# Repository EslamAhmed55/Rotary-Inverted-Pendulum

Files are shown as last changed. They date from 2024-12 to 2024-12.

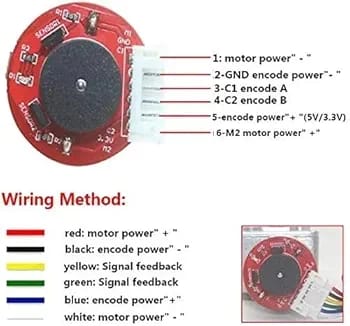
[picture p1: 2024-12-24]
HIL/Simulink/Motor Encoder.jpeg

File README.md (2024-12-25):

# Rotary Inverted Pendulum

## Overview
The **Rotary Inverted Pendulum** 
is a classic control systems project designed to model, simulate, and control a challenging mechanical system.
The system combines mechanical, electrical, and software components to achieve stabilization through advanced control techniques.

---

## Objectives
1. Develop a rotary inverted pendulum system as a demonstration of control engineering principles.
2. Model the system dynamics using Newton's Laws(for Simulation) and Euler-Lagrange(for HIL) methods.
3. Accurately estimate system parameters for reliable control.
4. Design and integrate mechanical components with an electronic control system.
5. Implement a Linear Quadratic Regulator (LQR) for stabilization.
6. Validate through simulation and Hardware-in-the-Loop (HIL) testing.
   


---

## Components
### Hardware
- **Arduino Uno**: Central processing unit for signal processing and control.
- **DC Motor with Encoder**: Provides rotational motion with position feedback.
- **Rotary Incremental Encoder**: Measures angular displacement and velocity.
- **H-Bridge**: Motor driver for bidirectional control.
- **Batteries, Bearings, and Couplings**: Supporting hardware for the system.
- **3D-Printed Parts**: Custom components like brackets and spacers.

  

---

### Software
- **SolidWorks**: For mechanical design and CAD modeling.
- **MATLAB & Simulink**: For simulation, parameter estimation, and HIL testing.

---

## Mechanical Design
The system includes:
1. **Base Structure**: Ensures stability and minimal vibration.
2. **Pendulum & Coupling**: Designed for smooth motion transmission.
3. **Bearing Assembly**: Reduces friction and aligns mechanical components.
4. **Motor and Encoder Mounts**: Ensures precise alignment and feedback.



---

## Hardware Circuit
The circuit integrates all components, ensuring seamless communication and precise control. Key considerations include:
- Proper grounding to minimize noise.
- Organized wiring for reduced interference.
- Overcurrent protection and thermal management.
  
  

---

## Parameter Estimation
System parameters were estimated by:
1. Collecting voltage and angular velocity data.
2. Using MATLAB's Parameter Estimation Toolbox.
3. Modeling and validating results in Simulink.
   
   
   
   

---

## Control Design
The project employs an **LQR Controller**:
1. Models the system dynamics and ensures controllability.
2. Minimizes a cost function to balance state performance and control effort.
3. Stabilizes the pendulum by placing system poles in the left-hand plane.

---
## Simulation

Simulations were conducted in MATLAB to:
1. Verify the system’s unstable dynamics.
2. Test the LQR controller for stability and performance.
3. Validate results with HIL testing using real hardware.

https://github.com/user-attachments/assets/a0bc8a6b-0416-4e09-b2ac-d904dfb135ff

---
## Hardware-in-the-Loop (HIL)

Hardware-in-the-Loop (HIL) testing was used to validate the system’s performance by integrating the control algorithm with real-world hardware. Using Simulink and the Arduino support package, the following steps were undertaken:
1. **Real-Time Simulation**: The controller algorithm was executed on a Simulink model interfaced with the Arduino.
2. **Hardware Validation**: Physical components, including the motor, encoder, and pendulum, were tested under real-world conditions.
3. **Testing and Refinement**: The results were analyzed to refine the control strategy and improve system stability.

   Capture

### Video Demonstration

https://github.com/user-attachments/assets/2c234a89-eb0c-4679-b708-453d3e55b6c0

---

## Resources
1. Research Paper: [Modeling and control of a rotary inverted pendulum](https://ieeexplore.ieee.org/document/5589450)
2. MATLAB Documentation: [LQR Control](https://www.mathworks.com/help/control/ref/lti.lqr.html)
3. Video Resources:
   - [Classic Inverted Pendulum - Equations of Motion](https://www.youtube.com/watch?v=5qJY-ZaKSic)
   - [LQR Controller Implementation](https://www.youtube.com/watch?v=E_RDCFOlJx4)

---

## Acknowledgments
I would like to extend my heartfelt gratitude to **Eng.Ahmed Farag** and **Eng.Ibrahim Abdelghafar** and **Eng.Mohab Ahmed Ali** for their invaluable guidance, support, and expertise throughout the project. Their assistance played a pivotal role in the successful completion of this work.

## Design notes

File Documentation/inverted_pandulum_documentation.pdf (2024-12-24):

# Mechatronics System

# Project: Rotary Inverted Pendulum Project

### Table of Contents

Objectives | 2
Components | 3
Mechanical design | 0
Hardware Circuit | 2
Parameter Estimation Steps | 3
Modelling | 8
1- Newton’s Laws | 8
2- Euler-Lagrange Method | 11
Control Design | 12
Simulation | 15
Hardware in the Loop | 17
Resources | 18

## Objectives

The rotary inverted pendulum is a widely recognized benchmark system in control engineering, known for its challenging dynamics and applications in advanced control design. This project aims to integrate mechanical, electrical, and software components to model, simulate, and control the system effectively. The following objectives outline the key aspects of the project: Develop a rotary inverted pendulum system to serve as a practical demonstration of advanced control engineering principles.

- Explore system modeling through Newton's Method and Lagrangian dynamics for a deeper understanding of mechanical behavior.
- Estimate system parameters accurately to ensure reliable modeling and control.
- Design and implement an efficient hardware circuit and integrate mechanical components with electronic control.
- Apply an LQR controller for stabilization, highlighting the principles of control design.
- Validate the control strategy through simulation and Hardware-in-the-Loop (HIL) testing.
- Document and utilize resources effectively to ensure the project's success.

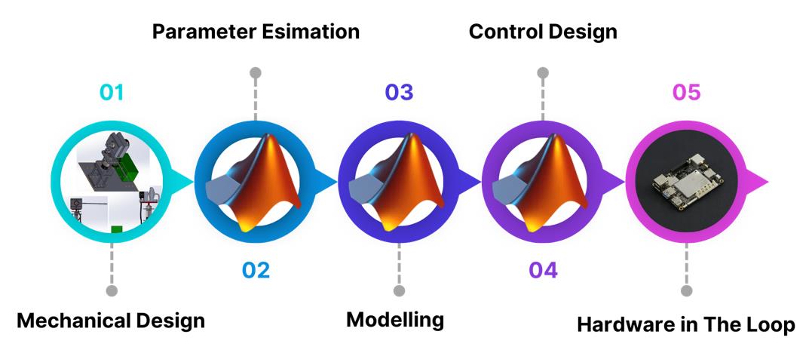
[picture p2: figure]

## Components

The hardware components used are:

❖ Arduino Uno

- A microcontroller board based on the
ATmega328P.

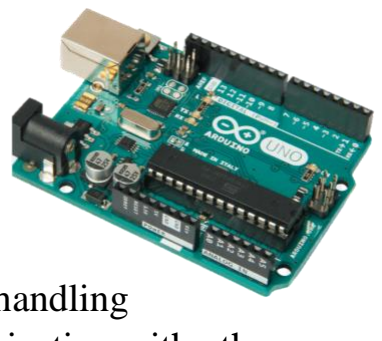
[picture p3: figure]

- Acts as the central processing unit for the system, handling
signal processing, control algorithms, and communication with other components.

❖ DC Motor with Encoder

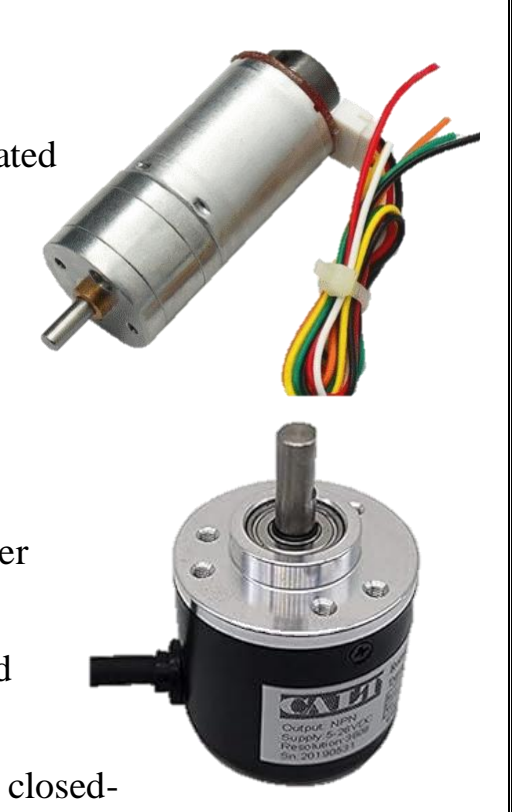
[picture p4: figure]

- A brushed DC motor equipped with an integrated encoder for precise speed and position feedback.
- Provides rotational motion to the pendulum base and enables control of its angular position.

❖ Rotary Incremental Encoder

- A high-resolution encoder with 1200 pulses per revolution (PPR).
- Used to measure the angular displacement and velocity of the pendulum.
- Provides essential feedback for implementing closed-loop control.

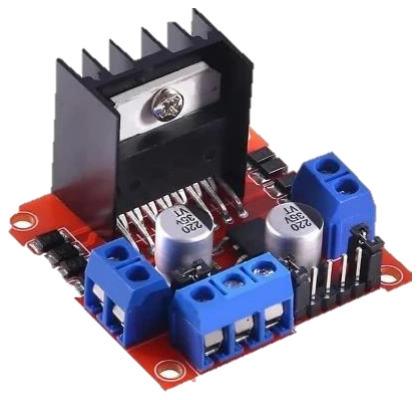
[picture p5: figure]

❖ H-Bridge

- A motor driver circuit that allows bidirectional control of the DC motor.

❖ 3 lithium Batteries

❖ Wires

❖ Bearing

❖ Coupling

❖ Pendulum

❖ 3D-Printing

❖ Spacers

## Mechanical design

The mechanical design of the rotary inverted pendulum was meticulously developed using SolidWorks, a powerful CAD software. The design process focused on creating a lightweight, precise, and stable structure capable of supporting the system's dynamic requirements. The following key components were modeled and integrated:

1. Base Structure
- Designed to provide a stable foundation for the pendulum system.
- Accommodates the DC motor, bearing, and other critical components.
- Ensures minimal vibrations and consistent performance during operation.
2. Pendulum
- Attached to the rotational axis with a secure coupling mechanism to ensure smooth motion.
3. Bearing Assembly
- Incorporated to reduce friction at the rotary axis and enable precise rotational motion.
- Positioned to align with the motor shaft for optimal mechanical efficiency.
4. Motor and Encoder Mount
- Custom brackets were designed to securely hold the DC motor and rotary incremental encoder.
- Ensures accurate alignment for precise feedback and smooth operation.
5. Coupling
- Designed to transmit torque from the motor shaft to the pendulum base with minimal energy loss.
- Accounts for minor misalignments to prevent undue stress on the motor or pendulum.
6. Spacer and Support Structures
- Used to maintain proper alignment and spacing between components.
- Ensures a compact and efficient layout for the entire system.
7. 3D-Printed Components
- Custom parts, including mounting brackets, pendulum holders, and spacers, were fabricated using 3D printing.

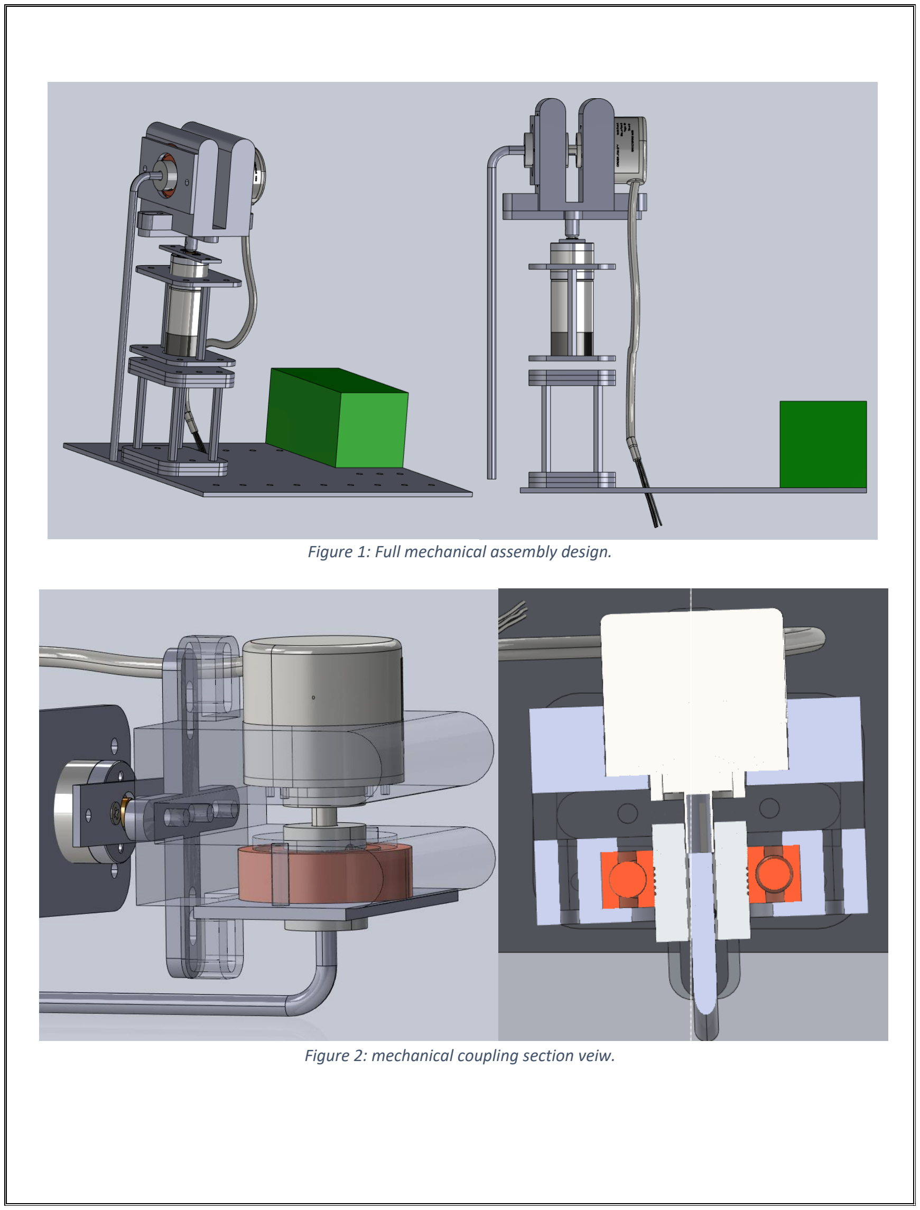
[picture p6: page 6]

Figure 1: Full mechanical assembly design.

Figure 2: mechanical coupling section veiw.

## Hardware Circuit

The hardware circuit for the rotary inverted pendulum system was designed to integrate all electrical components seamlessly, enabling precise control and stability. It connects the control unit, actuators, and feedback devices in a reliable and efficient manner.

Circuit Design Overview

- The Arduino Uno processes feedback signals from the rotary incremental encoder and implements the LQR control algorithm.
- The H-Bridge motor driver regulates the speed and direction of the DC motor based on PWM signals from the Arduino.
- The rotary encoder provides high-resolution position and velocity feedback, critical for accurate control.
- The power system, comprising lithium batteries, supplies sufficient energy to both the Arduino and the motor driver.

Wiring and Connections

- The motor driver is connected to the Arduino's PWM pins for motor speed control.
- The encoder outputs are linked to the Arduino's interrupt pins to capture high-frequency feedback signals.
- A dedicated power line is used for the motor driver to prevent noise interference with the Arduino.

Key Considerations

- Proper grounding was established to minimize noise and ensure signal integrity.
- Wiring was organized to prevent cross-interference, with signal and power lines routed separately.
- A heat sink was added to the H-Bridge to handle thermal loads during extended operation.
- Overcurrent protection was implemented to safeguard components during sudden load changes.

The hardware circuit ensures smooth communication between components, translating control commands into precise physical actions to stabilize the pendulum effectively.

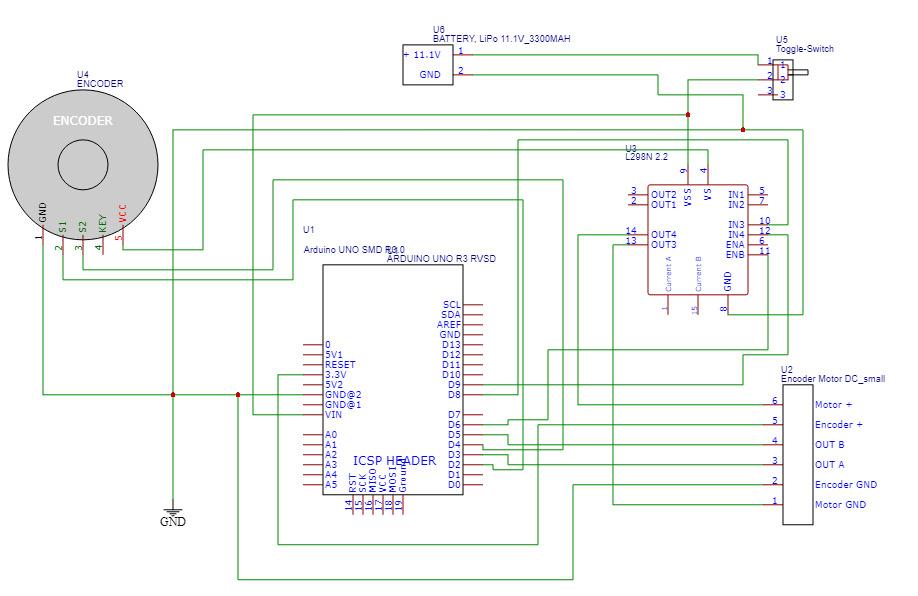
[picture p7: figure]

## Parameter Estimation Steps

Parameter estimation of a DC motor involves determining the values of various electrical and mechanical parameters that characterize the motor's behavior. These parameters are crucial for creating an accurate mathematical model of the DC motor, which is essential for designing effective control strategies. Parameter Estimation for the motor to get the motor coefficients:

- give the motor a Different Voltage signals using this circuit.

This circuit demonstrates how to control a DC motor with an encoder using variable voltage levels, generated by a potentiometer, for parameter estimation. Here's a brief explanation:

Components and Functionality:

1. Arduino UNO: Acts as the central microcontroller for reading signals and possibly controlling the system.
2. Battery (12V): Provides the primary power source for the DC motor.

Figure 3: Hardware circuit using easyEDA.

3. DC Motor with Encoder: The motor's encoder provides feedback on the rotational position or speed for parameter estimation.
4. Potentiometer: Used to vary the voltage signal that controls the motor speed.
5. Ammeter (Multimeter): Measures the current flow in the circuit, allowing calculation of motor parameters like resistance and torque constant.

Working:

- The potentiometer adjusts the voltage sent to the motor, enabling the control of motor speed.
- The Arduino reads encoder feedback to analyze the motor's response to the applied voltage.
- The ammeter monitors the current, aiding in parameter estimation such as motor resistance, inductance, and back EMF.
- The battery provides the required power for motor operation, while the Arduino manages low-power signal processing.

This setup helps in deriving key parameters of the motor, such as its torque constant, electrical resistance, and moment of inertia, by analyzing the relationship between voltage, current, and rotational speed.

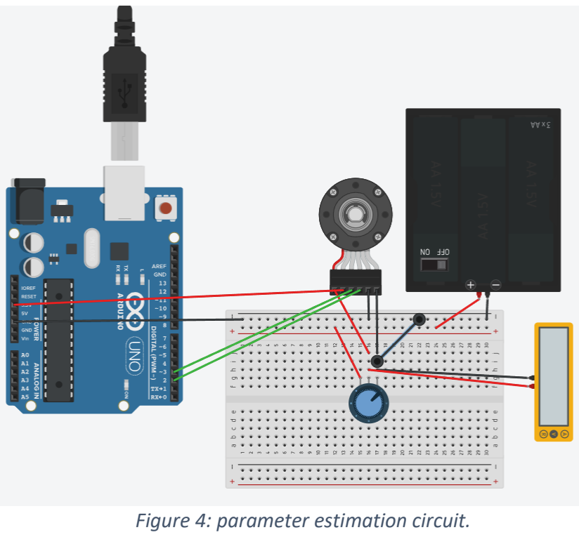
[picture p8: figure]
Figure 4: parameter estimation circuit.
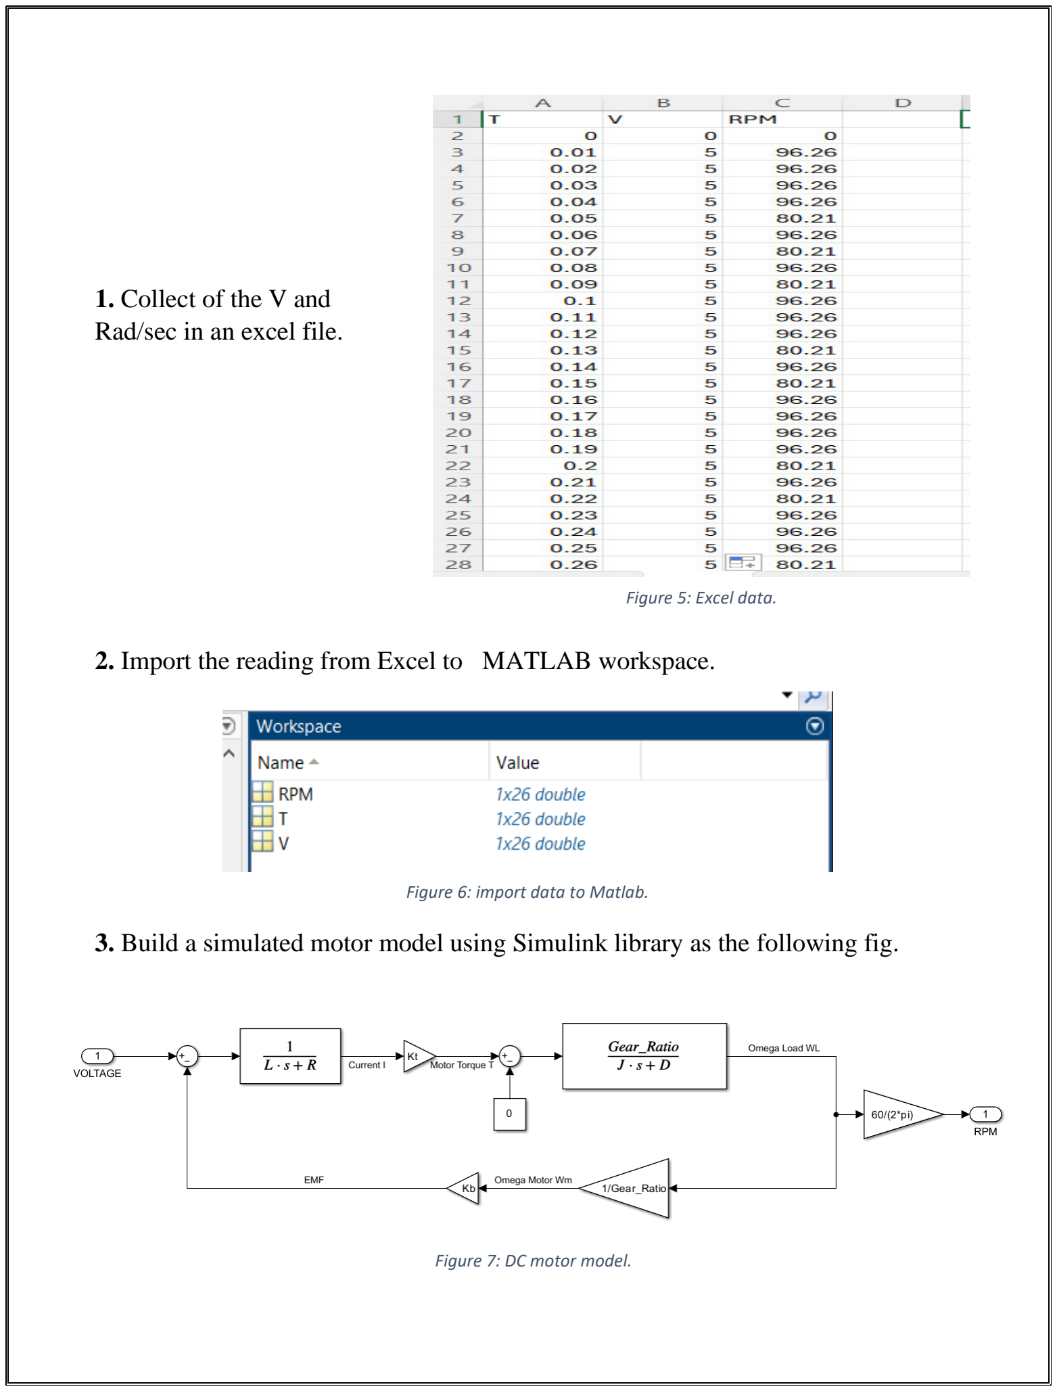
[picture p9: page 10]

### 1. Collect of the V and

Rad/sec in an excel file.

2. Import the reading from Excel to MATLAB workspace.
3. Build a simulated motor model using Simulink library as the following fig.

Figure 5: Excel data.

Figure 6: import data to Matlab.

Figure 7: DC motor model.

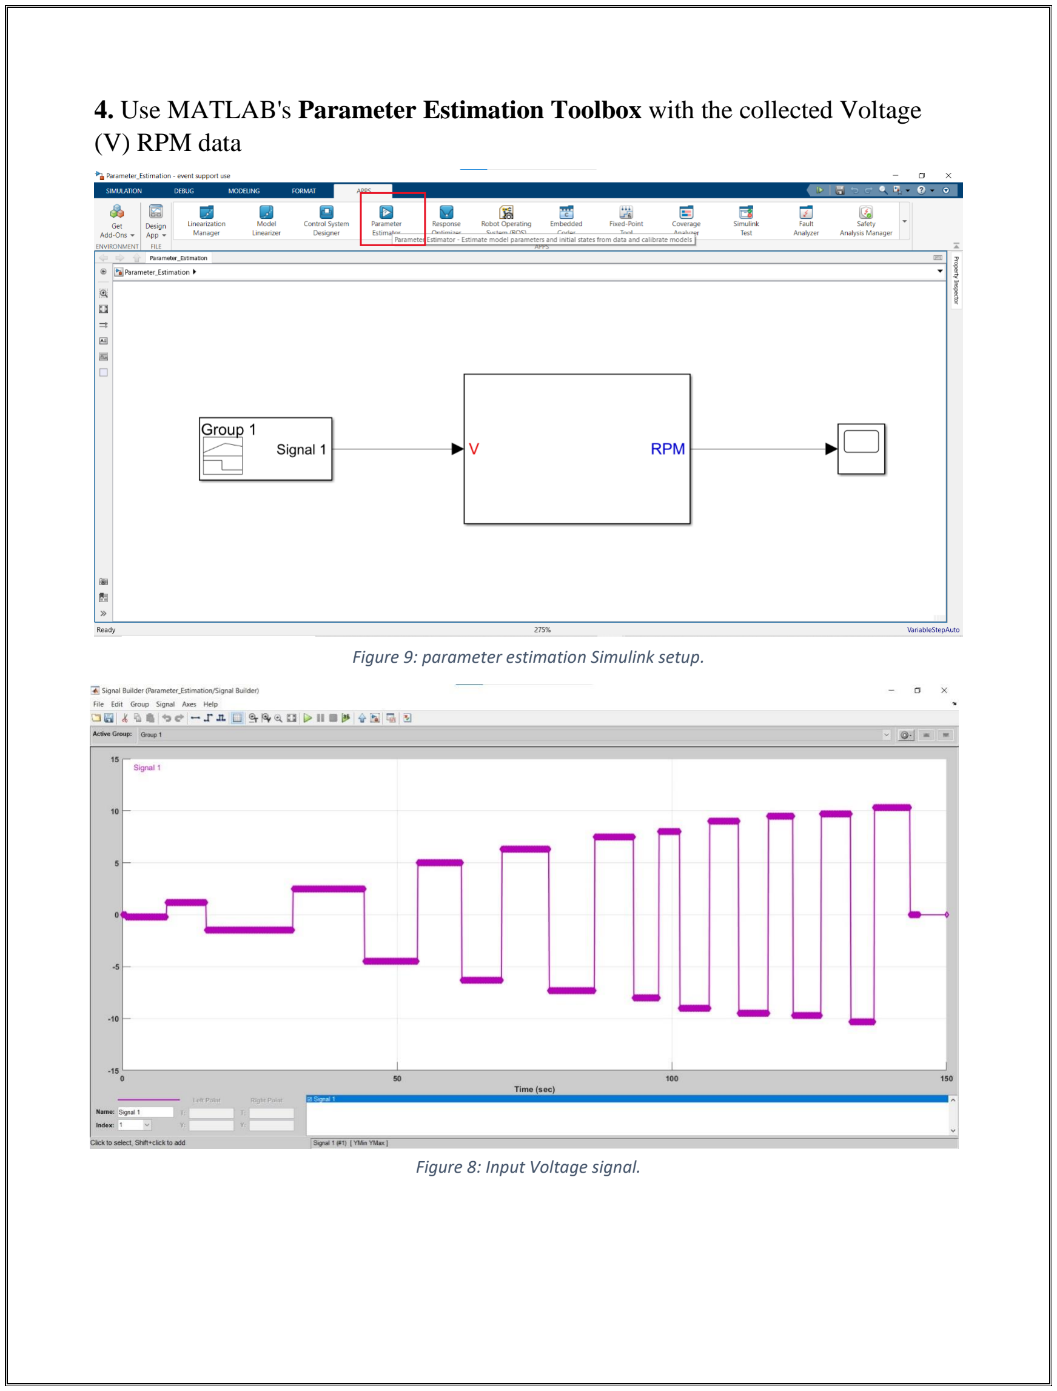
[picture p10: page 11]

### 4. Use MATLAB's Parameter Estimation Toolbox with the collected Voltage

(V) RPM data

Figure 9: parameter estimation Simulink setup.

Figure 8: Input Voltage signal.

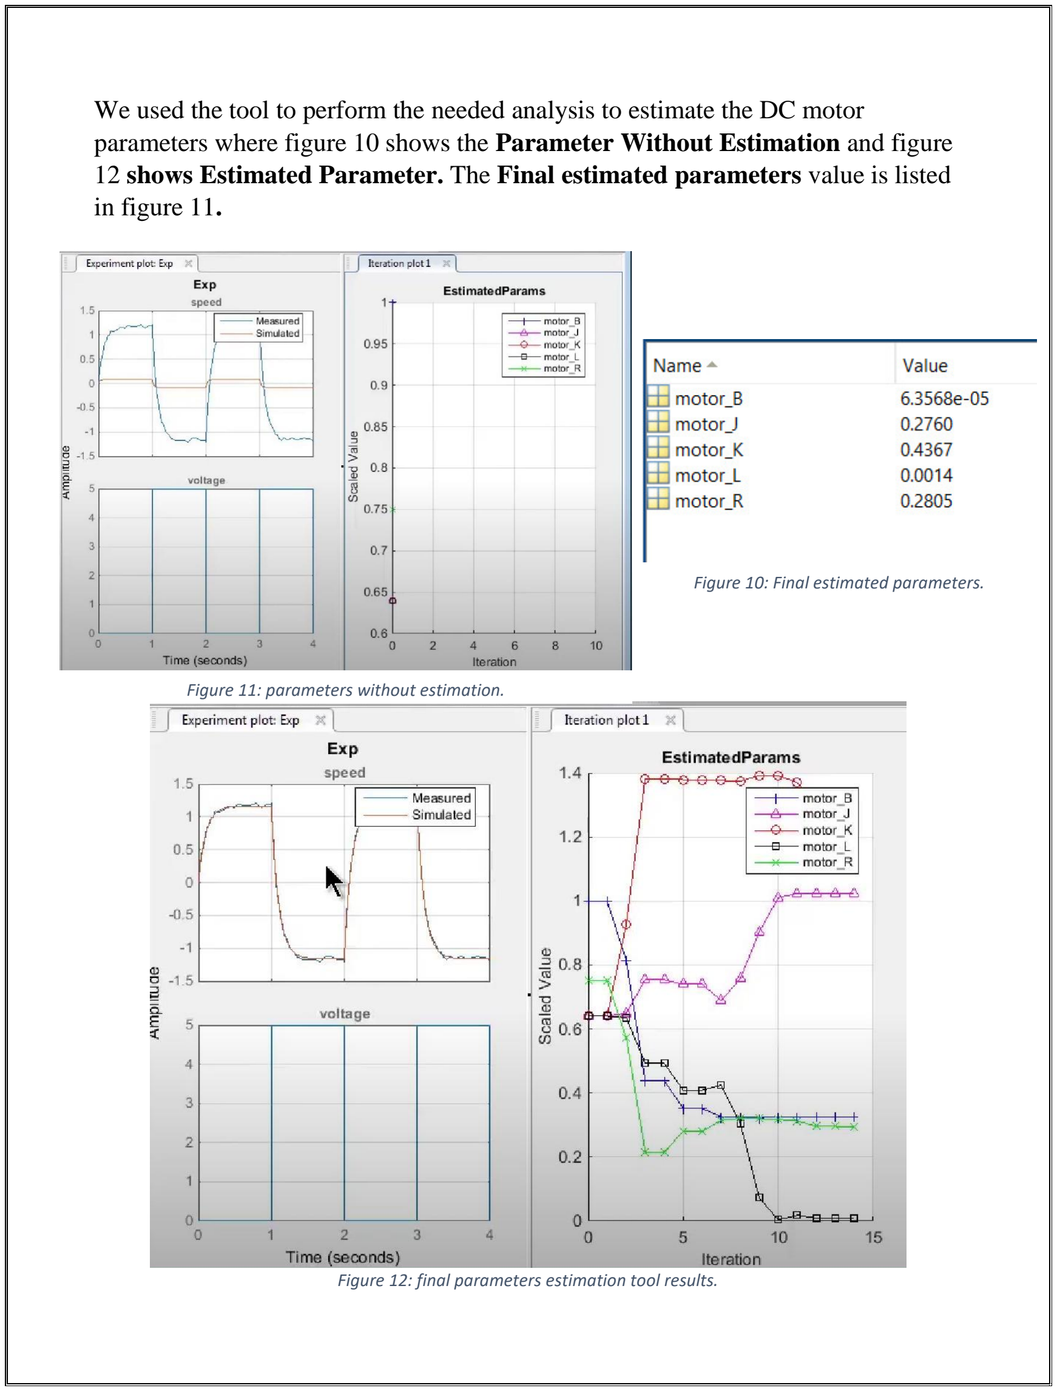
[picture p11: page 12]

We used the tool to perform the needed analysis to estimate the DC motor parameters where figure 10 shows the Parameter Without Estimation and figure 12 shows Estimated Parameter. The Final estimated parameters value is listed in figure 11.

Figure 11: parameters without estimation.

Figure 10: Final estimated parameters.

Figure 12: final parameters estimation tool results.

## Modelling

Modeling the rotary inverted pendulum is a crucial step in understanding its dynamic behavior and control characteristics. By developing an accurate mathematical representation of the system, we can analyze its response to various inputs and design effective control strategies. This modeling process involves the application of both Newtonian mechanics and Lagrangian dynamics to derive the equations of motion for the pendulum.

Using Newton's Method, we can establish a clear relationship between forces and motion, while Lagrangian mechanics provides a comprehensive framework for understanding energy conservation and the dynamics of the system. This dual approach allows for a robust analysis of the system's behavior, enabling us to simulate its performance under different conditions and optimize the control design for stability and responsiveness.

In the following sections, we will detail the methodologies employed in the modeling process, the resulting equations of motion, and the implications for control system design.

1- Newton’s Laws
Derived the equations of motion based on forces and torques as shown in figure 13.

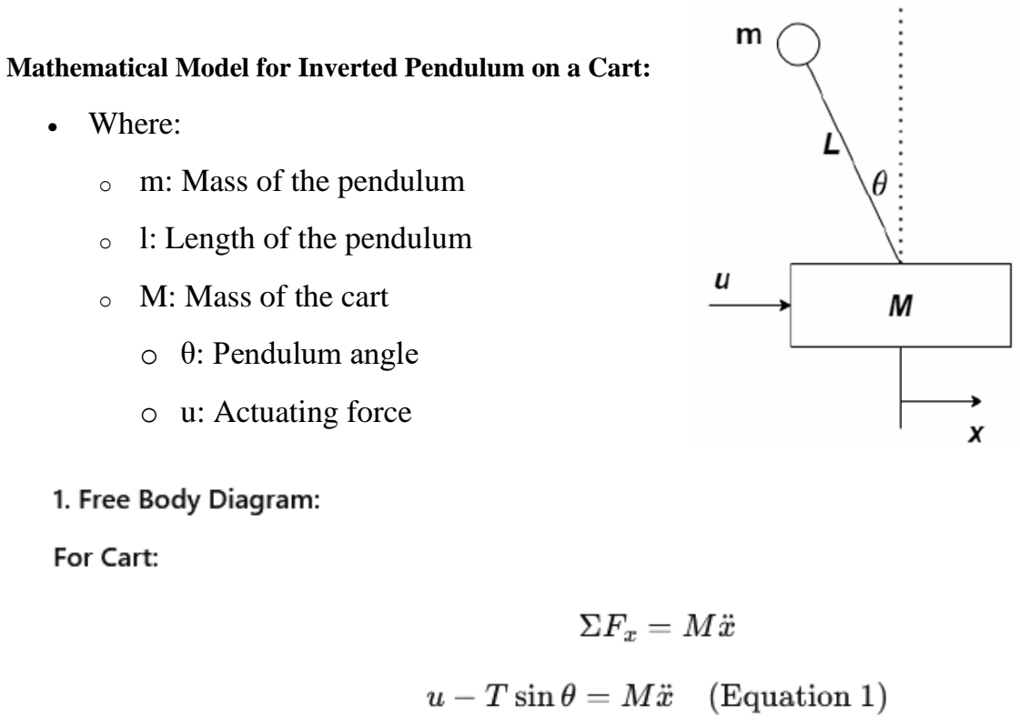
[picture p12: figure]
• Where:; • m: Mass of the pendulum; • l: Length of the pendulum; • M: Mass of the cart; • θ: Pendulum angle; • u: Actuating force

Mathematical Model for Inverted Pendulum on a Cart:

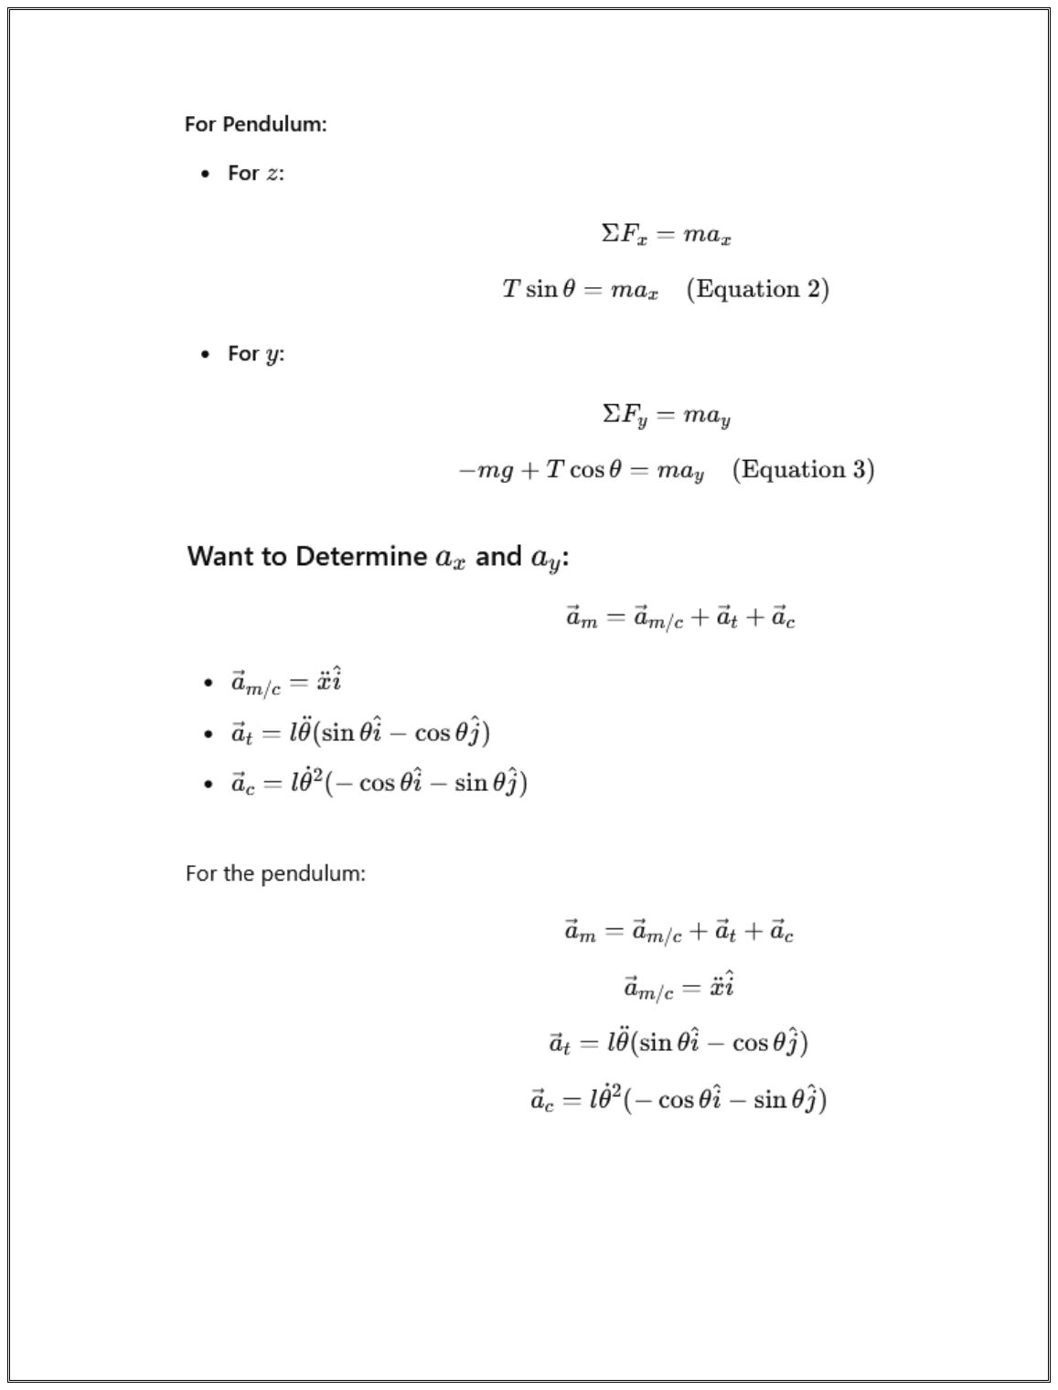
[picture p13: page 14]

The system consists of a cart with a mass (M), moving horizontally by input (u), with a massless rod with a length (L) holding a small mass (m), we want to keep the rod vertical (θ = Zero).

You can use Newtonian mechanics, or Euler-Lagrange equation to derive the equations of motion, but for the sake of brevity, you are given the equations in their final form.

We have two 2nd order differential equations, thus a total of 4 state variables is needed, selecting the states to be θ, θ’, x, x’

Then we need to linearize these non-linear equations and use them to build our Linear State Space Model. (Full proof is discussed in the extra resources section at the end) Important note, our linearized model is valid only around small angles.

if delta= 1 the model is linearized about the Upwards position and if delta= -1 the model is linearized about the downwards position.

Final State Space

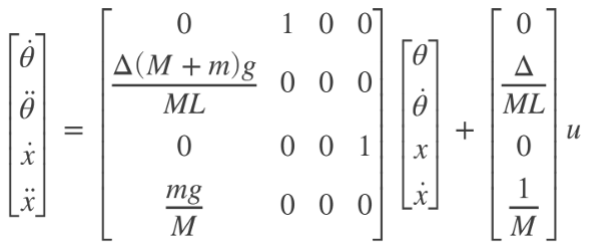
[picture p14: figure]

2- Euler-Lagrange Method

The Euler-Lagrange method is a powerful technique used to derive the equations of motion for dynamic systems, including the rotary inverted pendulum. This method is based on the principle of least action, which states that the path taken by a system between two states is the one for which the action integral is minimized. In this section, we apply the Euler-Lagrange formulation to our system, enabling us to model the dynamics effectively.

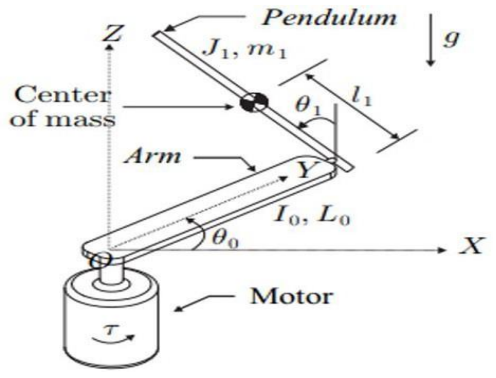
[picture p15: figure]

According to this paper” Modeling and control of a rotary inverted pendulum using various methods, comparative assessment and result analysis’’ We can conclude the state space shown below:

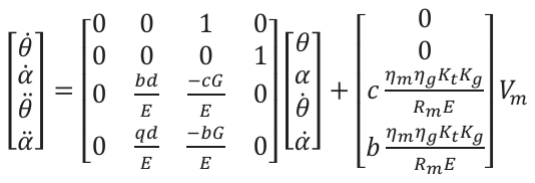
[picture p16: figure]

## Control Design

Before designing an LQR controller, controllability of the system must be verified. This ensures that the states of the system can be fully controlled using the input u(t)u(t)u(t). The system is controllable if the controllability matrix has full rank.

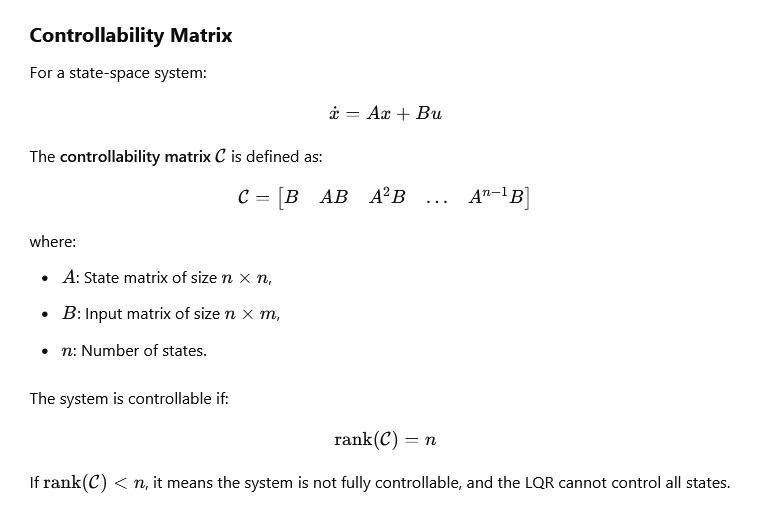
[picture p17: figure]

Why Controllability is Critical for LQR

- LQR relies on the ability to control all states of the system.
- Without controllability, some states cannot be regulated, leading to poor or unstable performance.

If the system is not controllable, consider redesigning the system, such as modifying A and B matrices, or adding actuators.

LQR Controller (Linear Quadratic Regulator) is an optimal control strategy used to design controllers for linear systems. It minimizes a cost function that balances state performance and control effort. LQR is widely applied in robotics, aerospace, and mechanical systems, including the inverted pendulum, robotic arms, and vehicle control.

Objective of LQR

To find an optimal control input u(t)u(t)u(t) for a linear system:

that minimizes the quadratic cost function:

where:

- x(t): State vector.
- u(t): Control input.
- A, B: System matrices.
- Q: State weighting matrix (penalizes deviations from the desired state).
- R: Control weighting matrix (penalizes excessive control effort).

Steps to Design an LQR Controller

### 1. Model the System

Obtain and linearize the state-space representation:

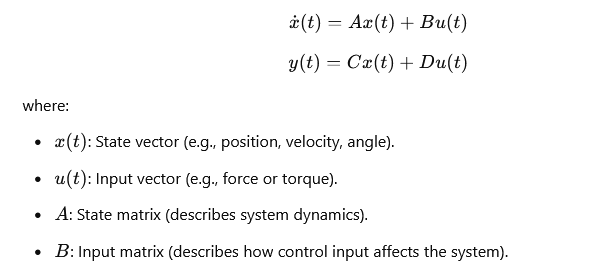
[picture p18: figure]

### 2. Choose the Weighting Matrices

Select the matrices Q and R:

- Q: Penalizes the deviation of states from their desired values. Larger values on the diagonal elements of Q increase the importance of minimizing specific states.
- R: Penalizes control effort. Larger values reduce control input magnitude, avoiding aggressive or excessive actuation.

Tip: Start with trial-and-error tuning of Q and R, then refine based on system response.

### 3. Solve the Algebraic Riccati Equation

Solve the Riccati equation to find the optimal state-feedback gain matrix K:

where P is a symmetric positive definite matrix. MATLAB or similar software tools can solve this equation numerically.

### 4. Compute the Gain Matrix KKK

The optimal feedback gain matrix K is:

This matrix defines how the control input u(t) is computed based on the current state x(t):

### 5. Implement the Controller

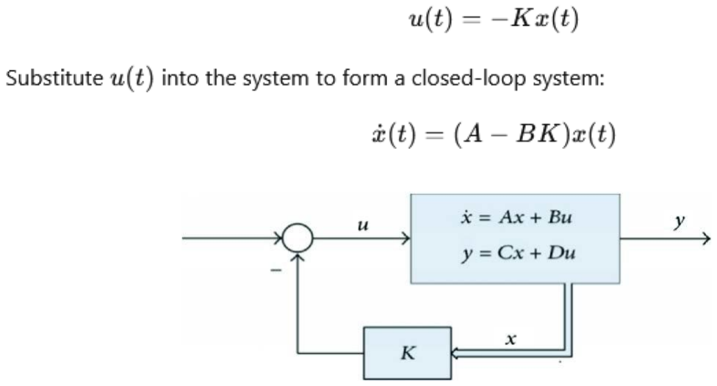
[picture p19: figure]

The control law becomes:

## Simulation

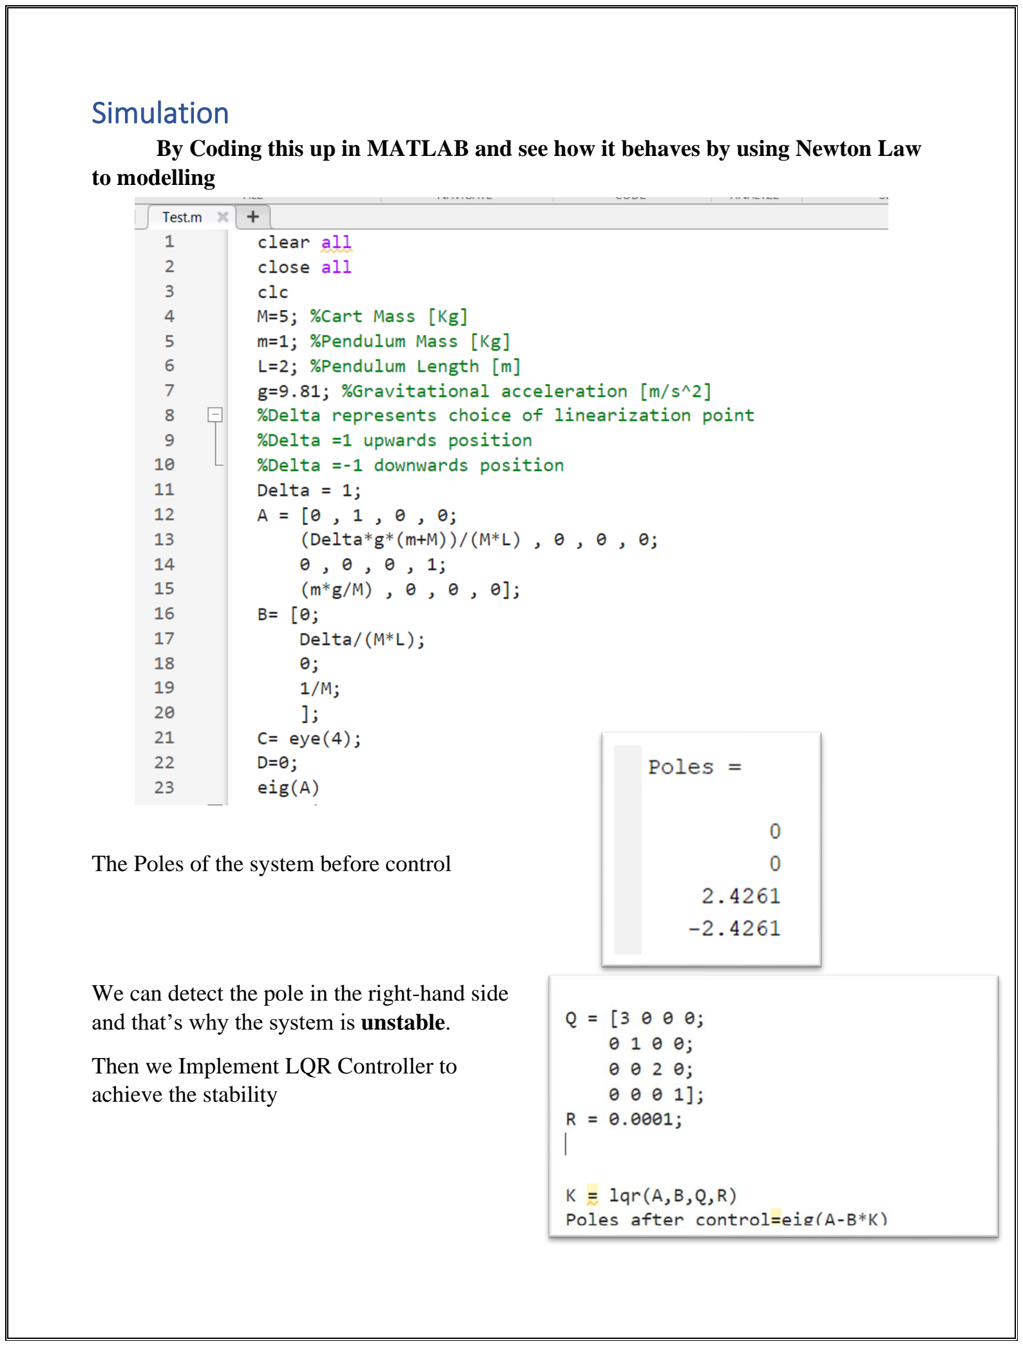
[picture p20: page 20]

By Coding this up in MATLAB and see how it behaves by using Newton Law to modelling

The Poles of the system before control

We can detect the pole in the right-hand side and that’s why the system is unstable.

Then we Implement LQR Controller to achieve the stability

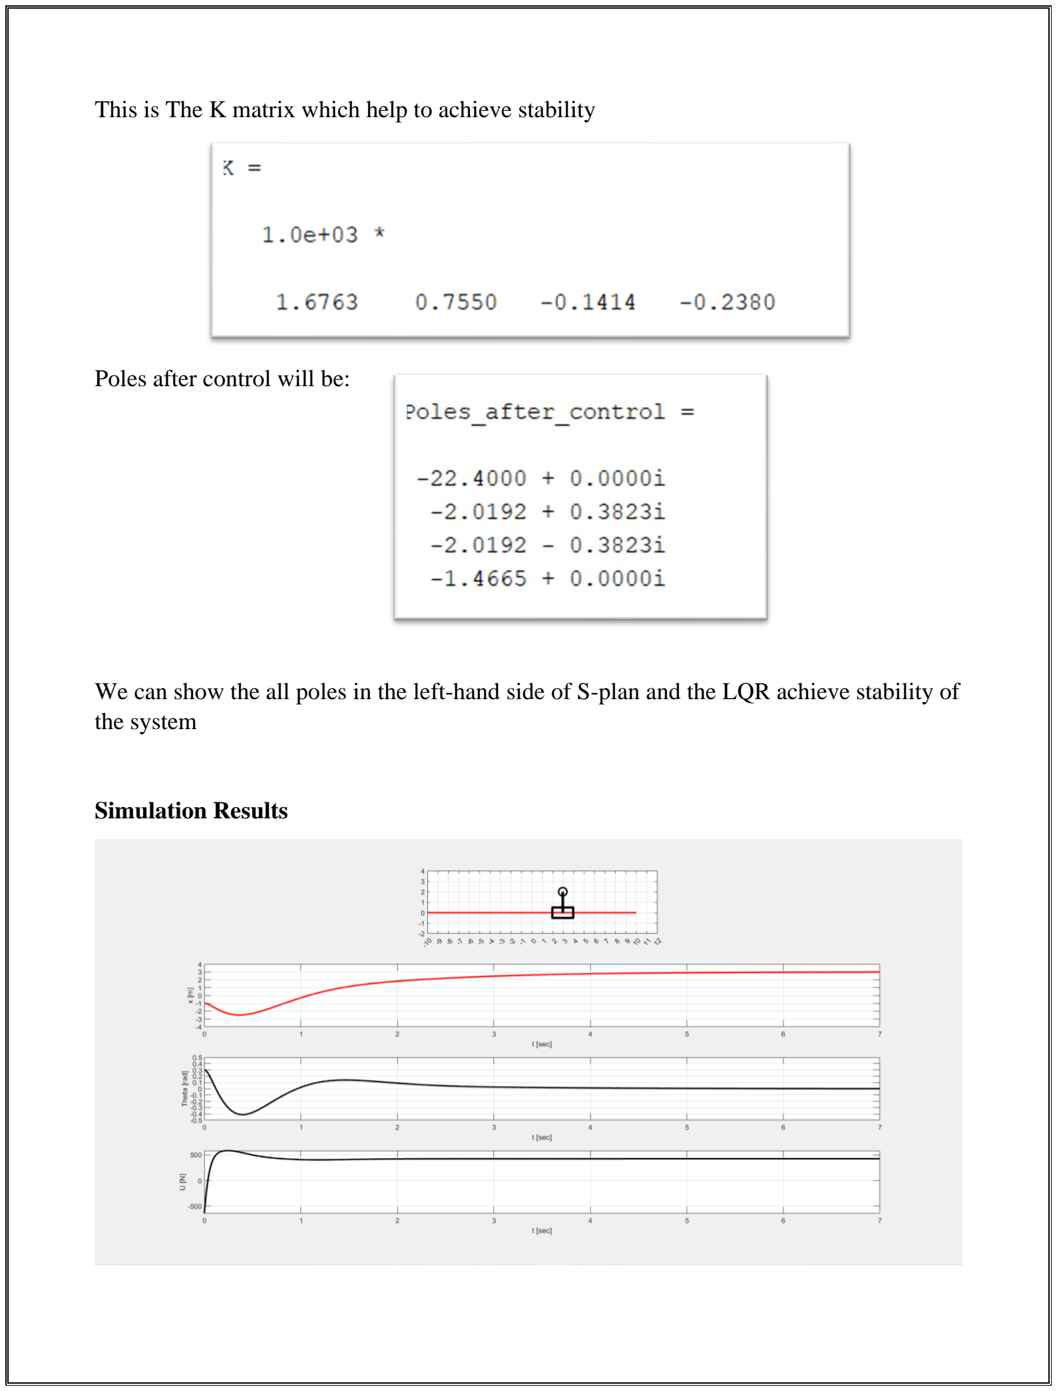
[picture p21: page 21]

This is The K matrix which help to achieve stability

Poles after control will be:

We can show the all poles in the left-hand side of S-plan and the LQR achieve stability of the system

Simulation Results

## Hardware in the Loop

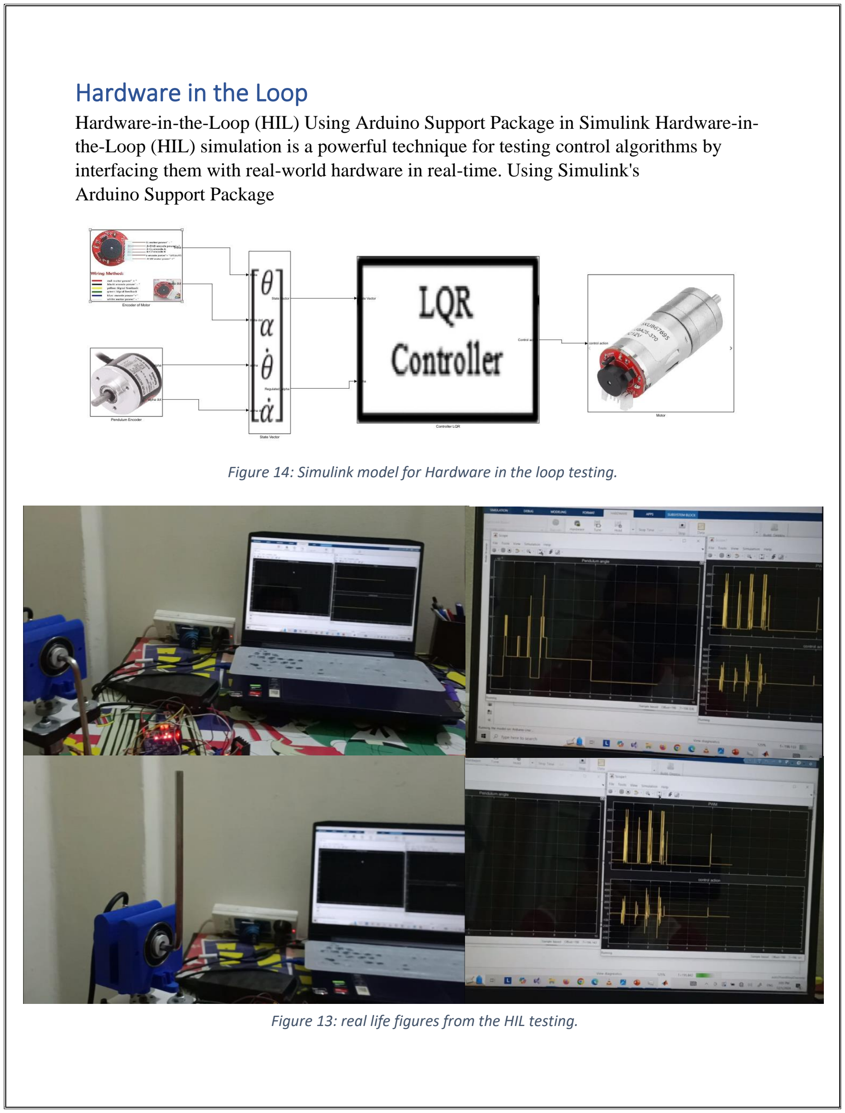
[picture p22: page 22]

Hardware-in-the-Loop (HIL) Using Arduino Support Package in Simulink Hardware-in-the-Loop (HIL) simulation is a powerful technique for testing control algorithms by interfacing them with real-world hardware in real-time. Using Simulink's
Arduino Support Package

Figure 14: Simulink model for Hardware in the loop testing.

Figure 13: real life figures from the HIL testing.

## Resources

❖ Paper “Modeling and control of a rotary inverted pendulum using various methods, comparative assessment and result analysis”

- https://ieeexplore.ieee.org/document/5589450

❖ LQR

- https://www.mathworks.com/help/control/ref/lti.lqr.html
- https://www.youtube.com/watch?v=E_RDCFOlJx4

❖ Classic Inverted Pendulum - Equations of Motion

- https://www.youtube.com/watch?v=5qJY-ZaKSic

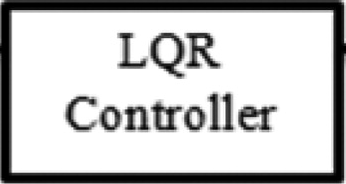
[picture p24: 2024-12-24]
HIL/Simulink/lqr.PNG

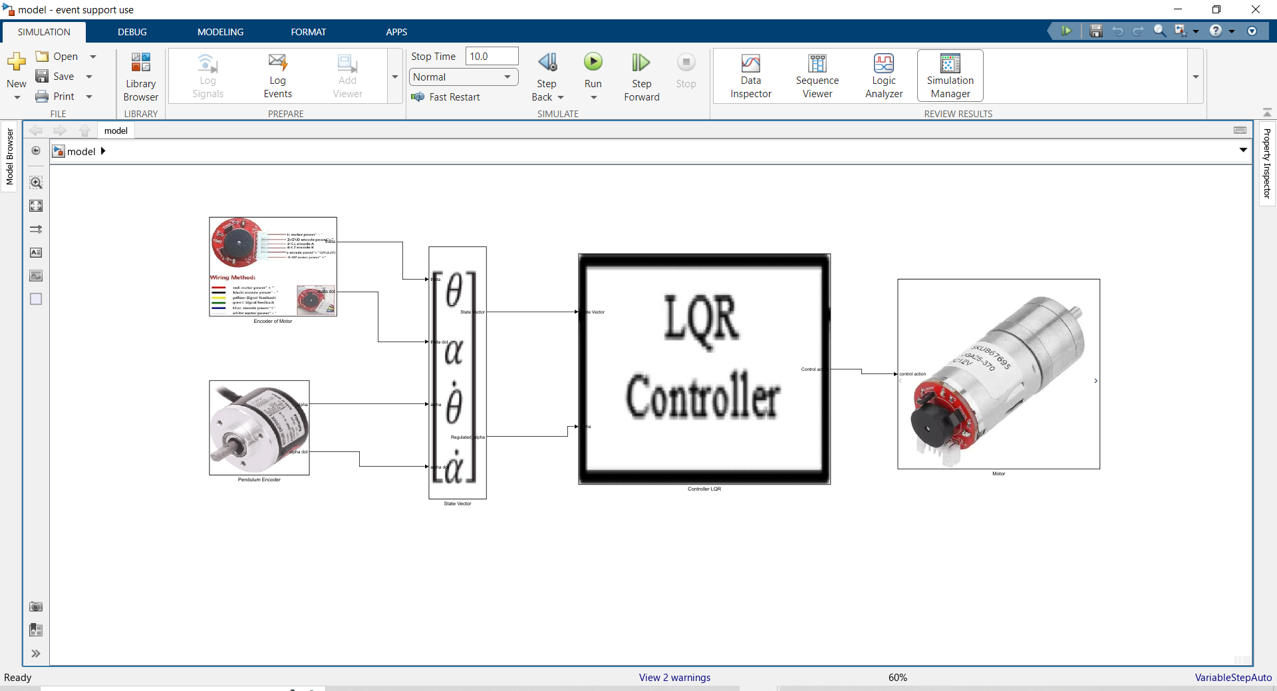
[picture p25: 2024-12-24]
HIL/Simulink/Capture.PNG

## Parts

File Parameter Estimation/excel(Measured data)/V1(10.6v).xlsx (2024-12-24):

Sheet: Sheet1
VOLT | RPM
10.6 | 256.68
10.6 | 240.64
10.6 | 256.68
10.6 | 272.73
10.6 | 256.68
10.6 | 256.68
10.6 | 256.68
10.6 | 256.68
10.6 | 256.68
10.6 | 256.68
10.6 | 224.6
10.6 | 256.68
10.6 | 256.68
10.6 | 256.68
10.6 | 240.64
10.6 | 256.68
10.6 | 256.68
10.6 | 272.73
10.6 | 224.6
10.6 | 272.73
10.6 | 256.68
10.6 | 256.68
10.6 | 272.73
10.6 | 256.68
10.6 | 256.68
10.6 | 256.68
10.6 | 256.68
10.6 | 224.6
10.6 | 256.68
10.6 | 256.68
10.6 | 256.68
10.6 | 224.6
10.6 | 256.68
10.6 | 256.68
10.6 | 256.68
10.6 | 240.64
10.6 | 256.68
10.6 | 256.68
10.6 | 272.73
10.6 | 256.68
10.6 | 240.64
10.6 | 256.68
10.6 | 256.68
10.6 | 272.73
10.6 | 224.6
10.6 | 272.73
10.6 | 256.68
10.6 | 256.68
10.6 | 240.64
10.6 | 256.68
10.6 | 256.68
10.6 | 256.68
10.6 | 224.6
10.6 | 256.68
10.6 | 256.68
10.6 | 256.68
10.6 | 256.68
10.6 | 256.68
10.6 | 256.68
10.6 | 272.73
10.6 | 256.68
10.6 | 240.64
10.6 | 256.68
10.6 | 256.68
10.6 | 272.73
10.6 | 224.6
10.6 | 272.73
10.6 | 256.68
10.6 | 256.68
10.6 | 240.64
10.6 | 256.68
10.6 | 256.68
10.6 | 256.68
10.6 | 256.68
10.6 | 256.68
10.6 | 256.68
10.6 | 256.68
10.6 | 256.68
10.6 | 224.6
10.6 | 256.68
10.6 | 272.73
10.6 | 256.68
10.6 | 240.64
10.6 | 256.68
10.6 | 256.68
10.6 | 272.73
10.6 | 224.6
10.6 | 256.68
10.6 | 256.68
10.6 | 256.68
10.6 | 256.68
10.6 | 224.6
10.6 | 256.68
10.6 | 256.68
10.6 | 256.68
10.6 | 240.64
10.6 | 256.68
10.6 | 256.68
10.6 | 272.73
10.6 | 224.6
10.6 | 272.73
10.6 | 256.68
10.6 | 256.68
10.6 | 240.64
10.6 | 256.68
10.6 | 256.68
10.6 | 272.73
10.6 | 256.68
10.6 | 256.68
10.6 | 272.73
10.6 | 256.68
10.6 | 256.68
10.6 | 240.64
10.6 | 256.68
10.6 | 256.68
10.6 | 256.68
10.6 | 224.6
10.6 | 256.68
10.6 | 256.68
10.6 | 256.68
10.6 | 240.64
10.6 | 256.68
10.6 | 256.68
10.6 | 256.68
10.6 | 256.68
10.6 | 256.68
10.6 | 256.68
10.6 | 256.68
10.6 | 256.68
10.6 | 240.64
10.6 | 256.68
10.6 | 272.73
10.6 | 256.68
10.6 | 240.64
10.6 | 256.68
10.6 | 256.68
10.6 | 256.68
10.6 | 224.6
10.6 | 256.68
10.6 | 256.68
10.6 | 256.68
10.6 | 256.68
10.6 | 224.6
10.6 | 256.68
10.6 | 272.73
10.6 | 256.68
10.6 | 240.64
10.6 | 256.68
10.6 | 256.68
10.6 | 272.73

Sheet: Data In
Data In (From USB-SERIAL CH340 (COM9))
Data coming from the current data source will appear below as it is received.
Current Data
TIME | CH1 | CH2 | CH3 | CH4 | CH5 | CH6 | CH7 | CH8 | CH9 | CH10
14:09:14 | 240.64
Historical Data
TIME | CH1 | CH2 | CH3 | CH4 | CH5 | CH6 | CH7 | CH8 | CH9 | CH10
14:09:14 | 256.68
14:09:14 | 240.64
14:09:14 | 256.68
14:09:14 | 272.73
14:09:14 | 256.68
14:09:14 | 256.68
14:09:14 | 256.68
14:09:14 | 256.68
14:09:14 | 256.68
14:09:14 | 256.68
14:09:14 | 224.6
14:09:14 | 256.68
14:09:14 | 256.68
14:09:14 | 256.68
14:09:14 | 240.64
14:09:14 | 256.68
14:09:14 | 256.68
14:09:14 | 272.73
14:09:14 | 224.6
14:09:14 | 272.73
14:09:14 | 256.68
14:09:14 | 256.68
14:09:14 | 272.73
14:09:14 | 256.68
14:09:14 | 256.68
14:09:14 | 256.68
14:09:14 | 256.68
14:09:14 | 224.6
14:09:14 | 256.68
14:09:14 | 256.68
14:09:14 | 256.68
14:09:14 | 224.6
14:09:14 | 256.68
14:09:14 | 256.68
14:09:14 | 256.68
14:09:14 | 240.64
14:09:14 | 256.68
14:09:14 | 256.68
14:09:14 | 272.73
14:09:14 | 256.68
14:09:14 | 240.64
14:09:14 | 256.68
14:09:14 | 256.68
14:09:14 | 272.73
14:09:14 | 224.6
14:09:14 | 272.73
14:09:14 | 256.68
14:09:14 | 256.68
14:09:14 | 240.64
14:09:14 | 256.68
14:09:14 | 256.68
14:09:14 | 256.68
14:09:14 | 224.6
14:09:14 | 256.68
14:09:14 | 256.68
14:09:14 | 256.68
14:09:14 | 256.68
14:09:14 | 256.68
14:09:14 | 256.68
14:09:14 | 272.73
14:09:14 | 256.68
14:09:14 | 240.64
14:09:13 | 256.68
14:09:13 | 256.68
14:09:13 | 272.73
14:09:13 | 224.6
14:09:13 | 272.73
14:09:13 | 256.68
14:09:13 | 256.68
14:09:13 | 240.64
14:09:13 | 256.68
14:09:13 | 256.68
14:09:13 | 256.68
14:09:13 | 256.68
14:09:13 | 256.68
14:09:13 | 256.68
14:09:13 | 256.68
14:09:13 | 256.68
14:09:13 | 224.6
14:09:13 | 256.68
14:09:13 | 272.73
14:09:13 | 256.68
14:09:13 | 240.64
14:09:13 | 256.68
14:09:13 | 256.68
14:09:13 | 272.73
14:09:13 | 224.6
14:09:13 | 256.68
14:09:13 | 256.68
14:09:13 | 256.68
14:09:13 | 256.68
14:09:13 | 224.6
14:09:13 | 256.68
14:09:13 | 256.68
14:09:13 | 256.68
14:09:13 | 240.64
14:09:13 | 256.68
14:09:13 | 256.68
14:09:13 | 272.73
14:09:13 | 224.6
14:09:13 | 272.73
14:09:13 | 256.68
14:09:13 | 256.68
14:09:13 | 240.64
14:09:13 | 256.68
14:09:13 | 256.68
14:09:13 | 272.73
14:09:13 | 256.68
14:09:13 | 256.68
14:09:13 | 272.73
14:09:13 | 256.68
14:09:13 | 256.68
14:09:13 | 240.64
14:09:13 | 256.68
14:09:13 | 256.68
14:09:13 | 256.68
14:09:13 | 224.6
14:09:13 | 256.68
14:09:13 | 256.68
14:09:13 | 256.68
14:09:13 | 240.64
14:09:13 | 256.68
14:09:13 | 256.68
14:09:13 | 256.68
14:09:13 | 256.68
14:09:13 | 256.68
14:09:13 | 256.68
14:09:13 | 256.68
14:09:13 | 256.68
14:09:13 | 240.64
14:09:13 | 256.68
14:09:13 | 272.73
14:09:13 | 256.68
14:09:13 | 240.64
14:09:13 | 256.68
14:09:13 | 256.68
14:09:13 | 256.68
14:09:13 | 224.6
14:09:13 | 256.68
14:09:13 | 256.68
14:09:13 | 256.68
14:09:13 | 256.68
14:09:13 | 224.6
14:09:13 | 256.68
14:09:13 | 272.73
14:09:13 | 256.68
14:09:13 | 240.64
14:09:13 | 256.68
14:09:13 | 256.68
14:09:13 | 272.73

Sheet: Data Out
Data Out (To Device)
Data entered into the channels below will be sent to the currently connected device as a comma-delimited string.
CH1 | CH2 | CH3 | CH4 | CH5 | CH6 | CH7 | CH8 | CH9 | CH10

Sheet: Settings
Workbook Settings
Settings below will affect how data is read into the current workbook from data sources. Clear a field's contents to revert to its default setting.
Data interval (ms) | 150 | 150
Data rows | 15 | 150
Data channels | 10 | 10
Data orientation | Newest last | Newest first
WARNING: Changing settings may result in the loss of content and/or custom formatting in the Data In and Data Out worksheets. Always save before changing values.

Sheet: Manifest
USB-SERIAL CH340 |  |  |  |  |  |  |  |  | {"Channels":[{"Description":null,"Id":null,"IsGhost":false,"Name":null,"Status":"Active","SubChannels":[{"Description":null,"Id":"CH1","IsGhost":false,"Name":"CH1","Status":"Active","SubChannels":[],"UnitOfMeasure":null},{"Description":null,"Id":"CH2","IsGhost":false,"Name":"CH2","Status":"Active","SubChannels":[],"UnitOfMeasure":null},{"Description":null,"Id":"CH3","IsGhost":false,"Name":"CH3","Status":"Active","SubChannels":[],"UnitOfMeasure":null},{"Description":null,"Id":"CH4","IsGhost":false,"Name":"CH4","Status":"Active","SubChannels":[],"UnitOfMeasure":null},{"Description":null,"Id":"CH5","IsGhost":false,"Name":"CH5","Status":"Active","SubChannels":[],"UnitOfMeasure":null},{"Description":null,"Id":"CH6","IsGhost":false,"Name":"CH6","Status":"Active","SubChannels":[],"UnitOfMeasure":null},{"Description":null,"Id":"CH7","IsGhost":false,"Name":"CH7","Status":"Active","SubChannels":[],"UnitOfMeasure":null},{"Description":null,"Id":"CH8","IsGhost":false,"Name":"CH8","Status":"Active","SubChannels":[],"UnitOfMeasure":null},{"Description":null,"Id":"CH9","IsGhost":false,"Name":"CH9","Status":"Active","SubChannels":[],"UnitOfMeasure":null},{"Description":null,"Id":"CH10","IsGhost":false,"Name":"CH10","Status":"Active","SubChannels":[],"UnitOfMeasure":null}],"UnitOfMeasure":null}],"Commands":[],"DataInterval":150,"Id":"A63C9D43-5A18-408D-8C59-6A948CC2EEDD","IsGenerated":true,"Name":"USB-SERIAL CH340","Version":null,"BaudRate":115200}
This manifest was generated for the connected device. You can edit the device name and channel data here and the Data In worksheet will be updated.
 | Channels
 |  |  |  |  |  |  | Data Source Id
 |  | Id | Name | Description | Unit of Measure | Active | A63C9D43-5A18-408D-8C59-6A948CC2EEDD | 1
 |  | CH1 | CH1 |  |  | ü | Data Interval (ms)
 |  | CH2 | CH2 |  |  | ü | 150
 |  | CH3 | CH3 |  |  | ü | Baud Rate
 |  | CH4 | CH4 |  |  | ü | 115200
 |  | CH5 | CH5 |  |  | ü
 |  | CH6 | CH6 |  |  | ü
 |  | CH7 | CH7 |  |  | ü
 |  | CH8 | CH8 |  |  | ü
 |  | CH9 | CH9 |  |  | ü
 |  | CH10 | CH10 |  |  | ü

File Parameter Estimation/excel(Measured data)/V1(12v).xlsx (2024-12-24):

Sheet: Sheet1
VOLT | RPM
12 | 272.73
12 | 304.81
12 | 304.81
12 | 272.73
12 | 288.77
12 | 288.77
12 | 304.81
12 | 272.73
12 | 304.81
12 | 288.77
12 | 304.81
12 | 272.73
12 | 304.81
12 | 288.77
12 | 304.81
12 | 304.81
12 | 304.81
12 | 288.77
12 | 304.81
12 | 304.81
12 | 272.73
12 | 288.77
12 | 304.81
12 | 304.81
12 | 272.73
12 | 288.77
12 | 288.77
12 | 304.81
12 | 272.73
12 | 304.81
12 | 288.77
12 | 304.81
12 | 304.81
12 | 272.73
12 | 288.77
12 | 304.81
12 | 304.81
12 | 272.73
12 | 288.77
12 | 304.81
12 | 304.81
12 | 272.73
12 | 288.77
12 | 288.77
12 | 304.81
12 | 272.73
12 | 288.77
12 | 288.77
12 | 304.81
12 | 304.81
12 | 288.77
12 | 288.77
12 | 304.81
12 | 304.81
12 | 272.73
12 | 288.77
12 | 304.81
12 | 304.81
12 | 272.73
12 | 288.77
12 | 288.77
12 | 304.81
12 | 272.73
12 | 304.81
12 | 288.77
12 | 304.81
12 | 304.81
12 | 288.77
12 | 288.77
12 | 304.81
12 | 304.81
12 | 272.73
12 | 288.77
12 | 288.77
12 | 304.81
12 | 272.73
12 | 288.77
12 | 288.77
12 | 304.81
12 | 272.73
12 | 304.81
12 | 288.77
12 | 304.81
12 | 304.81
12 | 272.73
12 | 288.77
12 | 304.81
12 | 304.81
12 | 272.73
12 | 288.77
12 | 288.77
12 | 304.81
12 | 272.73
12 | 288.77
12 | 288.77
12 | 304.81
12 | 272.73
12 | 304.81
12 | 288.77
12 | 304.81
12 | 304.81
12 | 304.81
12 | 288.77
12 | 304.81
12 | 304.81
12 | 272.73
12 | 288.77
12 | 304.81
12 | 304.81
12 | 272.73
12 | 288.77
12 | 288.77
12 | 304.81
12 | 272.73
12 | 288.77
12 | 288.77
12 | 304.81
12 | 304.81
12 | 288.77
12 | 288.77
12 | 304.81
12 | 304.81
12 | 256.68
12 | 288.77
12 | 304.81
12 | 304.81
12 | 272.73
12 | 288.77
12 | 304.81
12 | 304.81
12 | 272.73
12 | 304.81
12 | 288.77
12 | 304.81
12 | 304.81
12 | 272.73
12 | 288.77
12 | 304.81
12 | 304.81
12 | 272.73
12 | 288.77
12 | 288.77
12 | 304.81
12 | 272.73
12 | 304.81
12 | 288.77
12 | 304.81
12 | 272.73
12 | 304.81
12 | 288.77

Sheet: Data In
Data In (From USB-SERIAL CH340 (COM9))
Data coming from the current data source will appear below as it is received.
Current Data
TIME | CH1 | CH2 | CH3 | CH4 | CH5 | CH6 | CH7 | CH8 | CH9 | CH10
14:12:55 | 288.77
Historical Data
TIME | CH1 | CH2 | CH3 | CH4 | CH5 | CH6 | CH7 | CH8 | CH9 | CH10
14:12:55 | 288.77
14:12:55 | 304.81
14:12:55 | 304.81
14:12:55 | 272.73
14:12:55 | 288.77
14:12:55 | 288.77
14:12:55 | 304.81
14:12:55 | 272.73
14:12:55 | 304.81
14:12:55 | 288.77
14:12:55 | 304.81
14:12:55 | 272.73
14:12:55 | 304.81
14:12:55 | 288.77
14:12:55 | 304.81
14:12:55 | 304.81
14:12:55 | 304.81
14:12:55 | 288.77
14:12:55 | 304.81
14:12:55 | 304.81
14:12:55 | 272.73
14:12:55 | 288.77
14:12:55 | 304.81
14:12:55 | 304.81
14:12:55 | 272.73
14:12:55 | 288.77
14:12:55 | 288.77
14:12:55 | 304.81
14:12:55 | 272.73
14:12:55 | 304.81
14:12:55 | 288.77
14:12:55 | 304.81
14:12:55 | 304.81
14:12:55 | 272.73
14:12:55 | 288.77
14:12:55 | 304.81
14:12:55 | 304.81
14:12:55 | 272.73
14:12:55 | 288.77
14:12:55 | 304.81
14:12:55 | 304.81
14:12:55 | 272.73
14:12:55 | 288.77
14:12:55 | 288.77
14:12:55 | 304.81
14:12:55 | 272.73
14:12:55 | 288.77
14:12:55 | 288.77
14:12:55 | 304.81
14:12:55 | 304.81
14:12:55 | 288.77
14:12:55 | 288.77
14:12:55 | 304.81
14:12:55 | 304.81
14:12:55 | 272.73
14:12:55 | 288.77
14:12:55 | 304.81
14:12:55 | 304.81
14:12:55 | 272.73
14:12:55 | 288.77
14:12:55 | 288.77
14:12:55 | 304.81
14:12:55 | 272.73
14:12:55 | 304.81
14:12:55 | 288.77
14:12:55 | 304.81
14:12:55 | 304.81
14:12:55 | 288.77
14:12:55 | 288.77
14:12:55 | 304.81
14:12:55 | 304.81
14:12:55 | 272.73
14:12:55 | 288.77
14:12:54 | 288.77
14:12:54 | 304.81
14:12:54 | 272.73
14:12:54 | 288.77
14:12:54 | 288.77
14:12:54 | 304.81
14:12:54 | 272.73
14:12:54 | 304.81
14:12:54 | 288.77
14:12:54 | 304.81
14:12:54 | 304.81
14:12:54 | 272.73
14:12:54 | 288.77
14:12:54 | 304.81
14:12:54 | 304.81
14:12:54 | 272.73
14:12:54 | 288.77
14:12:54 | 288.77
14:12:54 | 304.81
14:12:54 | 272.73
14:12:54 | 288.77
14:12:54 | 288.77
14:12:54 | 304.81
14:12:54 | 272.73
14:12:54 | 304.81
14:12:54 | 288.77
14:12:54 | 304.81
14:12:54 | 304.81
14:12:54 | 304.81
14:12:54 | 288.77
14:12:54 | 304.81
14:12:54 | 304.81
14:12:54 | 272.73
14:12:54 | 288.77
14:12:54 | 304.81
14:12:54 | 304.81
14:12:54 | 272.73
14:12:54 | 288.77
14:12:54 | 288.77
14:12:54 | 304.81
14:12:54 | 272.73
14:12:54 | 288.77
14:12:54 | 288.77
14:12:54 | 304.81
14:12:54 | 304.81
14:12:54 | 288.77
14:12:54 | 288.77
14:12:54 | 304.81
14:12:54 | 304.81
14:12:54 | 256.68
14:12:54 | 288.77
14:12:54 | 304.81
14:12:54 | 304.81
14:12:54 | 272.73
14:12:54 | 288.77
14:12:54 | 304.81
14:12:54 | 304.81
14:12:54 | 272.73
14:12:54 | 304.81
14:12:54 | 288.77
14:12:54 | 304.81
14:12:54 | 304.81
14:12:54 | 272.73
14:12:54 | 288.77
14:12:54 | 304.81
14:12:54 | 304.81
14:12:54 | 272.73
14:12:54 | 288.77
14:12:54 | 288.77
14:12:54 | 304.81
14:12:54 | 272.73
14:12:54 | 304.81
14:12:54 | 288.77
14:12:54 | 304.81
14:12:54 | 272.73
14:12:54 | 304.81
14:12:54 | 288.77

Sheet: Data Out
Data Out (To Device)
Data entered into the channels below will be sent to the currently connected device as a comma-delimited string.
CH1 | CH2 | CH3 | CH4 | CH5 | CH6 | CH7 | CH8 | CH9 | CH10

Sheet: Settings
Workbook Settings
Settings below will affect how data is read into the current workbook from data sources. Clear a field's contents to revert to its default setting.
Data interval (ms) | 150 | 150
Data rows | 15 | 150
Data channels | 10 | 10
Data orientation | Newest last | Newest first
WARNING: Changing settings may result in the loss of content and/or custom formatting in the Data In and Data Out worksheets. Always save before changing values.

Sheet: Manifest
USB-SERIAL CH340 |  |  |  |  |  |  |  |  | {"Channels":[{"Description":null,"Id":null,"IsGhost":false,"Name":null,"Status":"Active","SubChannels":[{"Description":null,"Id":"CH1","IsGhost":false,"Name":"CH1","Status":"Active","SubChannels":[],"UnitOfMeasure":null},{"Description":null,"Id":"CH2","IsGhost":false,"Name":"CH2","Status":"Active","SubChannels":[],"UnitOfMeasure":null},{"Description":null,"Id":"CH3","IsGhost":false,"Name":"CH3","Status":"Active","SubChannels":[],"UnitOfMeasure":null},{"Description":null,"Id":"CH4","IsGhost":false,"Name":"CH4","Status":"Active","SubChannels":[],"UnitOfMeasure":null},{"Description":null,"Id":"CH5","IsGhost":false,"Name":"CH5","Status":"Active","SubChannels":[],"UnitOfMeasure":null},{"Description":null,"Id":"CH6","IsGhost":false,"Name":"CH6","Status":"Active","SubChannels":[],"UnitOfMeasure":null},{"Description":null,"Id":"CH7","IsGhost":false,"Name":"CH7","Status":"Active","SubChannels":[],"UnitOfMeasure":null},{"Description":null,"Id":"CH8","IsGhost":false,"Name":"CH8","Status":"Active","SubChannels":[],"UnitOfMeasure":null},{"Description":null,"Id":"CH9","IsGhost":false,"Name":"CH9","Status":"Active","SubChannels":[],"UnitOfMeasure":null},{"Description":null,"Id":"CH10","IsGhost":false,"Name":"CH10","Status":"Active","SubChannels":[],"UnitOfMeasure":null}],"UnitOfMeasure":null}],"Commands":[],"DataInterval":150,"Id":"1A51A6DE-2E40-45D9-8A01-398A94E9C606","IsGenerated":true,"Name":"USB-SERIAL CH340","Version":null,"BaudRate":115200}
This manifest was generated for the connected device. You can edit the device name and channel data here and the Data In worksheet will be updated.
 | Channels
 |  |  |  |  |  |  | Data Source Id
 |  | Id | Name | Description | Unit of Measure | Active | 1A51A6DE-2E40-45D9-8A01-398A94E9C606 | 1
 |  | CH1 | CH1 |  |  | ü | Data Interval (ms)
 |  | CH2 | CH2 |  |  | ü | 150
 |  | CH3 | CH3 |  |  | ü | Baud Rate
 |  | CH4 | CH4 |  |  | ü | 115200
 |  | CH5 | CH5 |  |  | ü
 |  | CH6 | CH6 |  |  | ü
 |  | CH7 | CH7 |  |  | ü
 |  | CH8 | CH8 |  |  | ü
 |  | CH9 | CH9 |  |  | ü
 |  | CH10 | CH10 |  |  | ü

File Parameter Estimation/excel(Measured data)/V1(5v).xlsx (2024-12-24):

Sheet: Sheet1
VOLT | RPM
5 | 128.34
5 | 112.3
5 | 112.3
5 | 112.3
5 | 112.3
5 | 112.3
5 | 128.34
5 | 96.26
5 | 112.3
5 | 128.34
5 | 112.3
5 | 96.26
5 | 128.34
5 | 112.3
5 | 112.3
5 | 112.3
5 | 112.3
5 | 112.3
5 | 112.3
5 | 112.3
5 | 112.3
5 | 112.3
5 | 128.34
5 | 112.3
5 | 112.3
5 | 112.3
5 | 112.3
5 | 112.3
5 | 96.26
5 | 112.3
5 | 112.3
5 | 112.3
5 | 96.26
5 | 112.3
5 | 112.3
5 | 112.3
5 | 112.3
5 | 112.3
5 | 112.3
5 | 112.3
5 | 128.34
5 | 112.3
5 | 112.3
5 | 112.3
5 | 128.34
5 | 96.26
5 | 112.3
5 | 112.3
5 | 112.3
5 | 96.26
5 | 112.3
5 | 128.34
5 | 112.3
5 | 96.26
5 | 128.34
5 | 112.3
5 | 112.3
5 | 112.3
5 | 112.3
5 | 112.3
5 | 112.3
5 | 112.3
5 | 96.26
5 | 112.3
5 | 112.3
5 | 128.34
5 | 96.26
5 | 112.3
5 | 128.34
5 | 112.3
5 | 96.26
5 | 128.34
5 | 112.3
5 | 112.3
5 | 112.3
5 | 128.34
5 | 112.3
5 | 112.3
5 | 112.3
5 | 112.3
5 | 112.3
5 | 112.3
5 | 112.3
5 | 112.3
5 | 112.3
5 | 112.3
5 | 128.34
5 | 96.26
5 | 112.3
5 | 128.34
5 | 112.3
5 | 112.3
5 | 112.3
5 | 112.3
5 | 128.34
5 | 112.3
5 | 96.26
5 | 128.34
5 | 112.3
5 | 112.3
5 | 112.3
5 | 112.3
5 | 112.3
5 | 112.3
5 | 112.3
5 | 112.3
5 | 112.3
5 | 112.3
5 | 112.3
5 | 96.26
5 | 112.3
5 | 128.34
5 | 112.3
5 | 96.26
5 | 128.34
5 | 112.3
5 | 112.3
5 | 112.3
5 | 112.3
5 | 112.3
5 | 112.3
5 | 112.3
5 | 112.3
5 | 112.3
5 | 112.3
5 | 128.34
5 | 112.3
5 | 112.3
5 | 112.3
5 | 128.34
5 | 96.26
5 | 112.3
5 | 128.34
5 | 112.3
5 | 96.26
5 | 128.34
5 | 112.3
5 | 112.3
5 | 96.26
5 | 128.34
5 | 112.3
5 | 112.3
5 | 112.3
5 | 128.34
5 | 112.3
5 | 112.3
5 | 112.3
5 | 112.3
5 | 112.3
5 | 112.3

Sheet: Data In
Data In (From USB-SERIAL CH340 (COM9))
Data coming from the current data source will appear below as it is received.
Current Data
TIME | CH1 | CH2 | CH3 | CH4 | CH5 | CH6 | CH7 | CH8 | CH9 | CH10
13:53:37 | 112.3
Historical Data
TIME | CH1 | CH2 | CH3 | CH4 | CH5 | CH6 | CH7 | CH8 | CH9 | CH10
13:53:37 | 112.3
13:53:37 | 112.3
13:53:37 | 112.3
13:53:37 | 112.3
13:53:37 | 112.3
13:53:37 | 112.3
13:53:37 | 128.34
13:53:37 | 96.26
13:53:37 | 112.3
13:53:37 | 128.34
13:53:37 | 112.3
13:53:37 | 96.26
13:53:37 | 128.34
13:53:37 | 112.3
13:53:37 | 112.3
13:53:37 | 112.3
13:53:37 | 112.3
13:53:37 | 112.3
13:53:37 | 112.3
13:53:36 | 112.3
13:53:36 | 112.3
13:53:36 | 112.3
13:53:36 | 128.34
13:53:36 | 112.3
13:53:36 | 112.3
13:53:36 | 112.3
13:53:36 | 112.3
13:53:36 | 112.3
13:53:36 | 96.26
13:53:36 | 112.3
13:53:36 | 112.3
13:53:36 | 112.3
13:53:36 | 96.26
13:53:36 | 112.3
13:53:36 | 112.3
13:53:36 | 112.3
13:53:36 | 112.3
13:53:36 | 112.3
13:53:36 | 112.3
13:53:36 | 112.3
13:53:36 | 128.34
13:53:36 | 112.3
13:53:36 | 112.3
13:53:36 | 112.3
13:53:36 | 128.34
13:53:36 | 96.26
13:53:36 | 112.3
13:53:36 | 112.3
13:53:36 | 112.3
13:53:36 | 96.26
13:53:36 | 112.3
13:53:36 | 128.34
13:53:36 | 112.3
13:53:36 | 96.26
13:53:36 | 128.34
13:53:36 | 112.3
13:53:36 | 112.3
13:53:36 | 112.3
13:53:36 | 112.3
13:53:36 | 112.3
13:53:36 | 112.3
13:53:36 | 112.3
13:53:36 | 96.26
13:53:36 | 112.3
13:53:36 | 112.3
13:53:36 | 128.34
13:53:36 | 96.26
13:53:36 | 112.3
13:53:36 | 128.34
13:53:36 | 112.3
13:53:36 | 96.26
13:53:36 | 128.34
13:53:36 | 112.3
13:53:36 | 112.3
13:53:36 | 112.3
13:53:36 | 128.34
13:53:36 | 112.3
13:53:36 | 112.3
13:53:36 | 112.3
13:53:36 | 112.3
13:53:36 | 112.3
13:53:36 | 112.3
13:53:36 | 112.3
13:53:36 | 112.3
13:53:36 | 112.3
13:53:36 | 112.3
13:53:36 | 128.34
13:53:36 | 96.26
13:53:36 | 112.3
13:53:36 | 128.34
13:53:36 | 112.3
13:53:36 | 112.3
13:53:36 | 112.3
13:53:36 | 112.3
13:53:36 | 128.34
13:53:36 | 112.3
13:53:36 | 96.26
13:53:36 | 128.34
13:53:36 | 112.3
13:53:36 | 112.3
13:53:36 | 112.3
13:53:36 | 112.3
13:53:36 | 112.3
13:53:36 | 112.3
13:53:36 | 112.3
13:53:36 | 112.3
13:53:36 | 112.3
13:53:36 | 112.3
13:53:36 | 112.3
13:53:36 | 96.26
13:53:36 | 112.3
13:53:36 | 128.34
13:53:36 | 112.3
13:53:36 | 96.26
13:53:36 | 128.34
13:53:36 | 112.3
13:53:36 | 112.3
13:53:36 | 112.3
13:53:36 | 112.3
13:53:35 | 112.3
13:53:35 | 112.3
13:53:35 | 112.3
13:53:35 | 112.3
13:53:35 | 112.3
13:53:35 | 112.3
13:53:35 | 128.34
13:53:35 | 112.3
13:53:35 | 112.3
13:53:35 | 112.3
13:53:35 | 128.34
13:53:35 | 96.26
13:53:35 | 112.3
13:53:35 | 128.34
13:53:35 | 112.3
13:53:35 | 96.26
13:53:35 | 128.34
13:53:35 | 112.3
13:53:35 | 112.3
13:53:35 | 96.26
13:53:35 | 128.34
13:53:35 | 112.3
13:53:35 | 112.3
13:53:35 | 112.3
13:53:35 | 128.34
13:53:35 | 112.3
13:53:35 | 112.3
13:53:35 | 112.3
13:53:35 | 112.3
13:53:35 | 112.3
13:53:35 | 112.3

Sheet: Data Out
Data Out (To Device)
Data entered into the channels below will be sent to the currently connected device as a comma-delimited string.
CH1 | CH2 | CH3 | CH4 | CH5 | CH6 | CH7 | CH8 | CH9 | CH10

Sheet: Settings
Workbook Settings
Settings below will affect how data is read into the current workbook from data sources. Clear a field's contents to revert to its default setting.
Data interval (ms) | 150 | 150
Data rows | 15 | 150
Data channels | 10 | 10
Data orientation | Newest last | Newest first
WARNING: Changing settings may result in the loss of content and/or custom formatting in the Data In and Data Out worksheets. Always save before changing values.

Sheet: Manifest
USB-SERIAL CH340 |  |  |  |  |  |  |  |  | {"Channels":[{"Description":null,"Id":null,"IsGhost":false,"Name":null,"Status":"Active","SubChannels":[{"Description":null,"Id":"CH1","IsGhost":false,"Name":"CH1","Status":"Active","SubChannels":[],"UnitOfMeasure":null},{"Description":null,"Id":"CH2","IsGhost":false,"Name":"CH2","Status":"Active","SubChannels":[],"UnitOfMeasure":null},{"Description":null,"Id":"CH3","IsGhost":false,"Name":"CH3","Status":"Active","SubChannels":[],"UnitOfMeasure":null},{"Description":null,"Id":"CH4","IsGhost":false,"Name":"CH4","Status":"Active","SubChannels":[],"UnitOfMeasure":null},{"Description":null,"Id":"CH5","IsGhost":false,"Name":"CH5","Status":"Active","SubChannels":[],"UnitOfMeasure":null},{"Description":null,"Id":"CH6","IsGhost":false,"Name":"CH6","Status":"Active","SubChannels":[],"UnitOfMeasure":null},{"Description":null,"Id":"CH7","IsGhost":false,"Name":"CH7","Status":"Active","SubChannels":[],"UnitOfMeasure":null},{"Description":null,"Id":"CH8","IsGhost":false,"Name":"CH8","Status":"Active","SubChannels":[],"UnitOfMeasure":null},{"Description":null,"Id":"CH9","IsGhost":false,"Name":"CH9","Status":"Active","SubChannels":[],"UnitOfMeasure":null},{"Description":null,"Id":"CH10","IsGhost":false,"Name":"CH10","Status":"Active","SubChannels":[],"UnitOfMeasure":null}],"UnitOfMeasure":null}],"Commands":[],"DataInterval":150,"Id":"60ED5D12-7764-4FFB-B6C8-6A6021C45552","IsGenerated":true,"Name":"USB-SERIAL CH340","Version":null,"BaudRate":115200}
This manifest was generated for the connected device. You can edit the device name and channel data here and the Data In worksheet will be updated.
 | Channels
 |  |  |  |  |  |  | Data Source Id
 |  | Id | Name | Description | Unit of Measure | Active | 60ED5D12-7764-4FFB-B6C8-6A6021C45552 | 1
 |  | CH1 | CH1 |  |  | ü | Data Interval (ms)
 |  | CH2 | CH2 |  |  | ü | 150
 |  | CH3 | CH3 |  |  | ü | Baud Rate
 |  | CH4 | CH4 |  |  | ü | 115200
 |  | CH5 | CH5 |  |  | ü
 |  | CH6 | CH6 |  |  | ü
 |  | CH7 | CH7 |  |  | ü
 |  | CH8 | CH8 |  |  | ü
 |  | CH9 | CH9 |  |  | ü
 |  | CH10 | CH10 |  |  | ü

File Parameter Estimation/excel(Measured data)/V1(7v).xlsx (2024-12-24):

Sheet: Sheet1
VOLT | RPM
7 | 160.43
7 | 144.39
7 | 160.43
7 | 176.47
7 | 160.43
7 | 160.43
7 | 160.43
7 | 176.47
7 | 160.43
7 | 144.39
7 | 160.43
7 | 160.43
7 | 176.47
7 | 160.43
7 | 176.47
7 | 160.43
7 | 176.47
7 | 160.43
7 | 160.43
7 | 160.43
7 | 160.43
7 | 176.47
7 | 144.39
7 | 176.47
7 | 160.43
7 | 176.47
7 | 144.39
7 | 176.47
7 | 160.43
7 | 160.43
7 | 160.43
7 | 160.43
7 | 176.47
7 | 160.43
7 | 176.47
7 | 144.39
7 | 176.47
7 | 160.43
7 | 160.43
7 | 144.39
7 | 160.43
7 | 176.47
7 | 160.43
7 | 160.43
7 | 160.43
7 | 176.47
7 | 160.43
7 | 160.43
7 | 144.39
7 | 160.43
7 | 176.47
7 | 160.43
7 | 160.43
7 | 160.43
7 | 176.47
7 | 160.43
7 | 144.39
7 | 160.43
7 | 160.43
7 | 176.47
7 | 144.39
7 | 176.47
7 | 160.43
7 | 160.43
7 | 160.43
7 | 160.43
7 | 176.47
7 | 160.43
7 | 176.47
7 | 144.39
7 | 176.47
7 | 160.43
7 | 176.47
7 | 144.39
7 | 160.43
7 | 176.47
7 | 160.43
7 | 160.43
7 | 160.43
7 | 176.47
7 | 160.43
7 | 160.43
7 | 176.47
7 | 160.43
7 | 176.47
7 | 160.43
7 | 160.43
7 | 160.43
7 | 160.43
7 | 160.43
7 | 144.39
7 | 176.47
7 | 160.43
7 | 176.47
7 | 144.39
7 | 160.43
7 | 160.43
7 | 160.43
7 | 176.47
7 | 144.39
7 | 176.47
7 | 160.43
7 | 160.43
7 | 144.39
7 | 160.43
7 | 176.47
7 | 160.43
7 | 160.43
7 | 160.43
7 | 160.43
7 | 176.47
7 | 144.39
7 | 176.47
7 | 160.43
7 | 176.47
7 | 160.43
7 | 160.43
7 | 160.43
7 | 160.43
7 | 176.47
7 | 144.39
7 | 176.47
7 | 160.43
7 | 160.43
7 | 160.43
7 | 160.43
7 | 176.47
7 | 160.43
7 | 144.39
7 | 160.43
7 | 160.43
7 | 176.47
7 | 160.43
7 | 176.47
7 | 160.43
7 | 160.43
7 | 160.43
7 | 144.39
7 | 176.47
7 | 160.43
7 | 176.47
7 | 144.39
7 | 160.43
7 | 160.43
7 | 160.43
7 | 160.43
7 | 160.43
7 | 176.47
7 | 160.43
7 | 160.43

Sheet: Data In
Data In (From USB-SERIAL CH340 (COM9))
Data coming from the current data source will appear below as it is received.
Current Data
TIME | CH1 | CH2 | CH3 | CH4 | CH5 | CH6 | CH7 | CH8 | CH9 | CH10
14:03:46 | 144.39
Historical Data
TIME | CH1 | CH2 | CH3 | CH4 | CH5 | CH6 | CH7 | CH8 | CH9 | CH10
14:03:46 | 176.47
14:03:46 | 144.39
14:03:46 | 160.43
14:03:46 | 176.47
14:03:46 | 160.43
14:03:46 | 160.43
14:03:46 | 160.43
14:03:46 | 176.47
14:03:46 | 160.43
14:03:46 | 144.39
14:03:46 | 160.43
14:03:46 | 160.43
14:03:46 | 176.47
14:03:46 | 160.43
14:03:46 | 176.47
14:03:46 | 160.43
14:03:46 | 176.47
14:03:46 | 160.43
14:03:46 | 160.43
14:03:46 | 160.43
14:03:46 | 160.43
14:03:46 | 176.47
14:03:46 | 144.39
14:03:46 | 176.47
14:03:46 | 160.43
14:03:46 | 176.47
14:03:46 | 144.39
14:03:46 | 176.47
14:03:46 | 160.43
14:03:46 | 160.43
14:03:46 | 160.43
14:03:46 | 160.43
14:03:46 | 176.47
14:03:46 | 160.43
14:03:46 | 176.47
14:03:46 | 144.39
14:03:46 | 176.47
14:03:46 | 160.43
14:03:46 | 160.43
14:03:46 | 144.39
14:03:46 | 160.43
14:03:46 | 176.47
14:03:46 | 160.43
14:03:46 | 160.43
14:03:46 | 160.43
14:03:46 | 176.47
14:03:46 | 160.43
14:03:46 | 160.43
14:03:46 | 144.39
14:03:46 | 160.43
14:03:46 | 176.47
14:03:46 | 160.43
14:03:45 | 160.43
14:03:45 | 160.43
14:03:45 | 176.47
14:03:45 | 160.43
14:03:45 | 144.39
14:03:45 | 160.43
14:03:45 | 160.43
14:03:45 | 176.47
14:03:45 | 144.39
14:03:45 | 176.47
14:03:45 | 160.43
14:03:45 | 160.43
14:03:45 | 160.43
14:03:45 | 160.43
14:03:45 | 176.47
14:03:45 | 160.43
14:03:45 | 176.47
14:03:45 | 144.39
14:03:45 | 176.47
14:03:45 | 160.43
14:03:45 | 176.47
14:03:45 | 144.39
14:03:45 | 160.43
14:03:45 | 176.47
14:03:45 | 160.43
14:03:45 | 160.43
14:03:45 | 160.43
14:03:45 | 176.47
14:03:45 | 160.43
14:03:45 | 160.43
14:03:45 | 176.47
14:03:45 | 160.43
14:03:45 | 176.47
14:03:45 | 160.43
14:03:45 | 160.43
14:03:45 | 160.43
14:03:45 | 160.43
14:03:45 | 160.43
14:03:45 | 144.39
14:03:45 | 176.47
14:03:45 | 160.43
14:03:45 | 176.47
14:03:45 | 144.39
14:03:45 | 160.43
14:03:45 | 160.43
14:03:45 | 160.43
14:03:45 | 176.47
14:03:45 | 144.39
14:03:45 | 176.47
14:03:45 | 160.43
14:03:45 | 160.43
14:03:45 | 144.39
14:03:45 | 160.43
14:03:45 | 176.47
14:03:45 | 160.43
14:03:45 | 160.43
14:03:45 | 160.43
14:03:45 | 160.43
14:03:45 | 176.47
14:03:45 | 144.39
14:03:45 | 176.47
14:03:45 | 160.43
14:03:45 | 176.47
14:03:45 | 160.43
14:03:45 | 160.43
14:03:45 | 160.43
14:03:45 | 160.43
14:03:45 | 176.47
14:03:45 | 144.39
14:03:45 | 176.47
14:03:45 | 160.43
14:03:45 | 160.43
14:03:45 | 160.43
14:03:45 | 160.43
14:03:45 | 176.47
14:03:45 | 160.43
14:03:45 | 144.39
14:03:45 | 160.43
14:03:45 | 160.43
14:03:45 | 176.47
14:03:45 | 160.43
14:03:45 | 176.47
14:03:45 | 160.43
14:03:45 | 160.43
14:03:45 | 160.43
14:03:45 | 144.39
14:03:45 | 176.47
14:03:45 | 160.43
14:03:45 | 176.47
14:03:45 | 144.39
14:03:45 | 160.43
14:03:45 | 160.43
14:03:45 | 160.43
14:03:45 | 160.43
14:03:45 | 160.43
14:03:45 | 176.47
14:03:45 | 160.43
14:03:45 | 160.43

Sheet: Data Out
Data Out (To Device)
Data entered into the channels below will be sent to the currently connected device as a comma-delimited string.
CH1 | CH2 | CH3 | CH4 | CH5 | CH6 | CH7 | CH8 | CH9 | CH10

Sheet: Settings
Workbook Settings
Settings below will affect how data is read into the current workbook from data sources. Clear a field's contents to revert to its default setting.
Data interval (ms) | 150 | 150
Data rows | 15 | 150
Data channels | 10 | 10
Data orientation | Newest last | Newest first
WARNING: Changing settings may result in the loss of content and/or custom formatting in the Data In and Data Out worksheets. Always save before changing values.

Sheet: Manifest
USB-SERIAL CH340 |  |  |  |  |  |  |  |  | {"Channels":[{"Description":null,"Id":null,"IsGhost":false,"Name":null,"Status":"Active","SubChannels":[{"Description":null,"Id":"CH1","IsGhost":false,"Name":"CH1","Status":"Active","SubChannels":[],"UnitOfMeasure":null},{"Description":null,"Id":"CH2","IsGhost":false,"Name":"CH2","Status":"Active","SubChannels":[],"UnitOfMeasure":null},{"Description":null,"Id":"CH3","IsGhost":false,"Name":"CH3","Status":"Active","SubChannels":[],"UnitOfMeasure":null},{"Description":null,"Id":"CH4","IsGhost":false,"Name":"CH4","Status":"Active","SubChannels":[],"UnitOfMeasure":null},{"Description":null,"Id":"CH5","IsGhost":false,"Name":"CH5","Status":"Active","SubChannels":[],"UnitOfMeasure":null},{"Description":null,"Id":"CH6","IsGhost":false,"Name":"CH6","Status":"Active","SubChannels":[],"UnitOfMeasure":null},{"Description":null,"Id":"CH7","IsGhost":false,"Name":"CH7","Status":"Active","SubChannels":[],"UnitOfMeasure":null},{"Description":null,"Id":"CH8","IsGhost":false,"Name":"CH8","Status":"Active","SubChannels":[],"UnitOfMeasure":null},{"Description":null,"Id":"CH9","IsGhost":false,"Name":"CH9","Status":"Active","SubChannels":[],"UnitOfMeasure":null},{"Description":null,"Id":"CH10","IsGhost":false,"Name":"CH10","Status":"Active","SubChannels":[],"UnitOfMeasure":null}],"UnitOfMeasure":null}],"Commands":[],"DataInterval":150,"Id":"A9810D2F-3FA0-4638-B07A-E7A3C717DA19","IsGenerated":true,"Name":"USB-SERIAL CH340","Version":null,"BaudRate":115200}
This manifest was generated for the connected device. You can edit the device name and channel data here and the Data In worksheet will be updated.
 | Channels
 |  |  |  |  |  |  | Data Source Id
 |  | Id | Name | Description | Unit of Measure | Active | A9810D2F-3FA0-4638-B07A-E7A3C717DA19 | 1
 |  | CH1 | CH1 |  |  | ü | Data Interval (ms)
 |  | CH2 | CH2 |  |  | ü | 150
 |  | CH3 | CH3 |  |  | ü | Baud Rate
 |  | CH4 | CH4 |  |  | ü | 115200
 |  | CH5 | CH5 |  |  | ü
 |  | CH6 | CH6 |  |  | ü
 |  | CH7 | CH7 |  |  | ü
 |  | CH8 | CH8 |  |  | ü
 |  | CH9 | CH9 |  |  | ü
 |  | CH10 | CH10 |  |  | ü

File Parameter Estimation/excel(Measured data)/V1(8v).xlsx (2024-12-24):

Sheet: Sheet1
VOLT | RPM
8 | 192.51
8 | 192.51
8 | 176.47
8 | 192.51
8 | 192.51
8 | 192.51
8 | 192.51
8 | 192.51
8 | 192.51
8 | 192.51
8 | 192.51
8 | 176.47
8 | 192.51
8 | 192.51
8 | 192.51
8 | 176.47
8 | 192.51
8 | 192.51
8 | 192.51
8 | 176.47
8 | 192.51
8 | 192.51
8 | 192.51
8 | 192.51
8 | 192.51
8 | 192.51
8 | 192.51
8 | 192.51
8 | 176.47
8 | 192.51
8 | 192.51
8 | 192.51
8 | 176.47
8 | 192.51
8 | 192.51
8 | 192.51
8 | 176.47
8 | 192.51
8 | 192.51
8 | 176.47
8 | 192.51
8 | 160.43
8 | 176.47
8 | 192.51
8 | 192.51
8 | 160.43
8 | 192.51
8 | 192.51
8 | 192.51
8 | 160.43
8 | 176.47
8 | 192.51
8 | 192.51
8 | 160.43
8 | 192.51
8 | 192.51
8 | 192.51
8 | 192.51
8 | 192.51
8 | 192.51
8 | 192.51
8 | 192.51
8 | 176.47
8 | 192.51
8 | 192.51
8 | 192.51
8 | 176.47
8 | 192.51
8 | 192.51
8 | 192.51
8 | 176.47
8 | 192.51
8 | 192.51
8 | 192.51
8 | 192.51
8 | 192.51
8 | 192.51
8 | 176.47
8 | 192.51
8 | 160.43
8 | 192.51
8 | 192.51
8 | 192.51
8 | 176.47
8 | 192.51
8 | 192.51
8 | 192.51
8 | 176.47
8 | 192.51
8 | 192.51
8 | 192.51
8 | 192.51
8 | 176.47
8 | 192.51
8 | 192.51
8 | 192.51
8 | 176.47
8 | 192.51
8 | 192.51
8 | 192.51
8 | 176.47
8 | 192.51
8 | 192.51
8 | 192.51
8 | 176.47
8 | 192.51
8 | 192.51
8 | 192.51
8 | 192.51
8 | 192.51
8 | 192.51
8 | 192.51
8 | 192.51
8 | 160.43
8 | 192.51
8 | 192.51
8 | 192.51
8 | 160.43
8 | 192.51
8 | 208.56
8 | 192.51
8 | 160.43
8 | 208.56
8 | 192.51
8 | 192.51
8 | 192.51
8 | 192.51
8 | 192.51
8 | 192.51
8 | 192.51
8 | 176.47
8 | 192.51
8 | 192.51
8 | 192.51
8 | 176.47
8 | 192.51
8 | 192.51
8 | 192.51
8 | 176.47
8 | 192.51
8 | 192.51
8 | 192.51
8 | 192.51
8 | 176.47
8 | 192.51
8 | 192.51
8 | 192.51
8 | 176.47
8 | 192.51
8 | 192.51

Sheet: Data In
Data In (From USB-SERIAL CH340 (COM9))
Data coming from the current data source will appear below as it is received.
Current Data
TIME | CH1 | CH2 | CH3 | CH4 | CH5 | CH6 | CH7 | CH8 | CH9 | CH10
14:05:15 | 192.51
Historical Data
TIME | CH1 | CH2 | CH3 | CH4 | CH5 | CH6 | CH7 | CH8 | CH9 | CH10
14:05:15 | 192.51
14:05:15 | 192.51
14:05:15 | 176.47
14:05:15 | 192.51
14:05:15 | 192.51
14:05:15 | 192.51
14:05:15 | 192.51
14:05:15 | 192.51
14:05:15 | 192.51
14:05:15 | 192.51
14:05:15 | 192.51
14:05:15 | 176.47
14:05:15 | 192.51
14:05:15 | 192.51
14:05:15 | 192.51
14:05:15 | 176.47
14:05:15 | 192.51
14:05:15 | 192.51
14:05:15 | 192.51
14:05:15 | 176.47
14:05:15 | 192.51
14:05:15 | 192.51
14:05:15 | 192.51
14:05:15 | 192.51
14:05:15 | 192.51
14:05:15 | 192.51
14:05:15 | 192.51
14:05:15 | 192.51
14:05:15 | 176.47
14:05:15 | 192.51
14:05:15 | 192.51
14:05:15 | 192.51
14:05:15 | 176.47
14:05:15 | 192.51
14:05:15 | 192.51
14:05:15 | 192.51
14:05:15 | 176.47
14:05:15 | 192.51
14:05:15 | 192.51
14:05:15 | 176.47
14:05:15 | 192.51
14:05:15 | 160.43
14:05:15 | 176.47
14:05:15 | 192.51
14:05:15 | 192.51
14:05:15 | 160.43
14:05:15 | 192.51
14:05:15 | 192.51
14:05:15 | 192.51
14:05:15 | 160.43
14:05:15 | 176.47
14:05:15 | 192.51
14:05:15 | 192.51
14:05:15 | 160.43
14:05:15 | 192.51
14:05:15 | 192.51
14:05:15 | 192.51
14:05:15 | 192.51
14:05:15 | 192.51
14:05:15 | 192.51
14:05:15 | 192.51
14:05:15 | 192.51
14:05:15 | 176.47
14:05:15 | 192.51
14:05:15 | 192.51
14:05:15 | 192.51
14:05:15 | 176.47
14:05:15 | 192.51
14:05:15 | 192.51
14:05:15 | 192.51
14:05:15 | 176.47
14:05:15 | 192.51
14:05:15 | 192.51
14:05:15 | 192.51
14:05:15 | 192.51
14:05:15 | 192.51
14:05:15 | 192.51
14:05:15 | 176.47
14:05:15 | 192.51
14:05:15 | 160.43
14:05:15 | 192.51
14:05:15 | 192.51
14:05:15 | 192.51
14:05:15 | 176.47
14:05:15 | 192.51
14:05:15 | 192.51
14:05:15 | 192.51
14:05:15 | 176.47
14:05:15 | 192.51
14:05:15 | 192.51
14:05:15 | 192.51
14:05:15 | 192.51
14:05:15 | 176.47
14:05:15 | 192.51
14:05:15 | 192.51
14:05:14 | 192.51
14:05:14 | 176.47
14:05:14 | 192.51
14:05:14 | 192.51
14:05:14 | 192.51
14:05:14 | 176.47
14:05:14 | 192.51
14:05:14 | 192.51
14:05:14 | 192.51
14:05:14 | 176.47
14:05:14 | 192.51
14:05:14 | 192.51
14:05:14 | 192.51
14:05:14 | 192.51
14:05:14 | 192.51
14:05:14 | 192.51
14:05:14 | 192.51
14:05:14 | 192.51
14:05:14 | 160.43
14:05:14 | 192.51
14:05:14 | 192.51
14:05:14 | 192.51
14:05:14 | 160.43
14:05:14 | 192.51
14:05:14 | 208.56
14:05:14 | 192.51
14:05:14 | 160.43
14:05:14 | 208.56
14:05:14 | 192.51
14:05:14 | 192.51
14:05:14 | 192.51
14:05:14 | 192.51
14:05:14 | 192.51
14:05:14 | 192.51
14:05:14 | 192.51
14:05:14 | 176.47
14:05:14 | 192.51
14:05:14 | 192.51
14:05:14 | 192.51
14:05:14 | 176.47
14:05:14 | 192.51
14:05:14 | 192.51
14:05:14 | 192.51
14:05:14 | 176.47
14:05:14 | 192.51
14:05:14 | 192.51
14:05:14 | 192.51
14:05:14 | 192.51
14:05:14 | 176.47
14:05:14 | 192.51
14:05:14 | 192.51
14:05:14 | 192.51
14:05:14 | 176.47
14:05:14 | 192.51
14:05:14 | 192.51

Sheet: Data Out
Data Out (To Device)
Data entered into the channels below will be sent to the currently connected device as a comma-delimited string.
CH1 | CH2 | CH3 | CH4 | CH5 | CH6 | CH7 | CH8 | CH9 | CH10

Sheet: Settings
Workbook Settings
Settings below will affect how data is read into the current workbook from data sources. Clear a field's contents to revert to its default setting.
Data interval (ms) | 150 | 150
Data rows | 15 | 150
Data channels | 10 | 10
Data orientation | Newest last | Newest first
WARNING: Changing settings may result in the loss of content and/or custom formatting in the Data In and Data Out worksheets. Always save before changing values.

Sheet: Manifest
USB-SERIAL CH340 |  |  |  |  |  |  |  |  | {"Channels":[{"Description":null,"Id":null,"IsGhost":false,"Name":null,"Status":"Active","SubChannels":[{"Description":null,"Id":"CH1","IsGhost":false,"Name":"CH1","Status":"Active","SubChannels":[],"UnitOfMeasure":null},{"Description":null,"Id":"CH2","IsGhost":false,"Name":"CH2","Status":"Active","SubChannels":[],"UnitOfMeasure":null},{"Description":null,"Id":"CH3","IsGhost":false,"Name":"CH3","Status":"Active","SubChannels":[],"UnitOfMeasure":null},{"Description":null,"Id":"CH4","IsGhost":false,"Name":"CH4","Status":"Active","SubChannels":[],"UnitOfMeasure":null},{"Description":null,"Id":"CH5","IsGhost":false,"Name":"CH5","Status":"Active","SubChannels":[],"UnitOfMeasure":null},{"Description":null,"Id":"CH6","IsGhost":false,"Name":"CH6","Status":"Active","SubChannels":[],"UnitOfMeasure":null},{"Description":null,"Id":"CH7","IsGhost":false,"Name":"CH7","Status":"Active","SubChannels":[],"UnitOfMeasure":null},{"Description":null,"Id":"CH8","IsGhost":false,"Name":"CH8","Status":"Active","SubChannels":[],"UnitOfMeasure":null},{"Description":null,"Id":"CH9","IsGhost":false,"Name":"CH9","Status":"Active","SubChannels":[],"UnitOfMeasure":null},{"Description":null,"Id":"CH10","IsGhost":false,"Name":"CH10","Status":"Active","SubChannels":[],"UnitOfMeasure":null}],"UnitOfMeasure":null}],"Commands":[],"DataInterval":150,"Id":"29192BD9-F019-49ED-8A06-068E4EB79F4D","IsGenerated":true,"Name":"USB-SERIAL CH340","Version":null,"BaudRate":115200}
This manifest was generated for the connected device. You can edit the device name and channel data here and the Data In worksheet will be updated.
 | Channels
 |  |  |  |  |  |  | Data Source Id
 |  | Id | Name | Description | Unit of Measure | Active | 29192BD9-F019-49ED-8A06-068E4EB79F4D | 1
 |  | CH1 | CH1 |  |  | ü | Data Interval (ms)
 |  | CH2 | CH2 |  |  | ü | 150
 |  | CH3 | CH3 |  |  | ü | Baud Rate
 |  | CH4 | CH4 |  |  | ü | 115200
 |  | CH5 | CH5 |  |  | ü
 |  | CH6 | CH6 |  |  | ü
 |  | CH7 | CH7 |  |  | ü
 |  | CH8 | CH8 |  |  | ü
 |  | CH9 | CH9 |  |  | ü
 |  | CH10 | CH10 |  |  | ü

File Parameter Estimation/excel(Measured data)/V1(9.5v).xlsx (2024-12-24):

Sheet: Sheet1
VOLT | RPM
9.5 | 240.64
9.5 | 224.6
9.5 | 208.56
9.5 | 240.64
9.5 | 224.6
9.5 | 240.64
9.5 | 224.6
9.5 | 240.64
9.5 | 224.6
9.5 | 240.64
9.5 | 224.6
9.5 | 208.56
9.5 | 240.64
9.5 | 224.6
9.5 | 240.64
9.5 | 208.56
9.5 | 224.6
9.5 | 240.64
9.5 | 224.6
9.5 | 208.56
9.5 | 224.6
9.5 | 224.6
9.5 | 224.6
9.5 | 224.6
9.5 | 208.56
9.5 | 224.6
9.5 | 240.64
9.5 | 224.6
9.5 | 208.56
9.5 | 240.64
9.5 | 224.6
9.5 | 240.64
9.5 | 208.56
9.5 | 224.6
9.5 | 240.64
9.5 | 224.6
9.5 | 208.56
9.5 | 240.64
9.5 | 224.6
9.5 | 240.64
9.5 | 224.6
9.5 | 240.64
9.5 | 224.6
9.5 | 224.6
9.5 | 224.6
9.5 | 192.51
9.5 | 224.6
9.5 | 240.64
9.5 | 224.6
9.5 | 208.56
9.5 | 240.64
9.5 | 224.6
9.5 | 240.64
9.5 | 208.56
9.5 | 224.6
9.5 | 240.64
9.5 | 224.6
9.5 | 240.64
9.5 | 224.6
9.5 | 240.64
9.5 | 224.6
9.5 | 224.6
9.5 | 208.56
9.5 | 240.64
9.5 | 224.6
9.5 | 240.64
9.5 | 208.56
9.5 | 224.6
9.5 | 240.64
9.5 | 224.6
9.5 | 208.56
9.5 | 240.64
9.5 | 224.6
9.5 | 240.64
9.5 | 224.6
9.5 | 208.56
9.5 | 224.6
9.5 | 240.64
9.5 | 224.6
9.5 | 208.56
9.5 | 240.64
9.5 | 224.6
9.5 | 240.64
9.5 | 208.56
9.5 | 224.6
9.5 | 240.64
9.5 | 224.6
9.5 | 208.56
9.5 | 224.6
9.5 | 224.6
9.5 | 224.6
9.5 | 224.6
9.5 | 224.6
9.5 | 240.64
9.5 | 224.6
9.5 | 240.64
9.5 | 208.56
9.5 | 224.6
9.5 | 240.64
9.5 | 224.6
9.5 | 208.56
9.5 | 240.64
9.5 | 224.6
9.5 | 240.64
9.5 | 208.56
9.5 | 240.64
9.5 | 224.6
9.5 | 240.64
9.5 | 224.6
9.5 | 240.64
9.5 | 224.6
9.5 | 240.64
9.5 | 224.6
9.5 | 208.56
9.5 | 240.64
9.5 | 224.6
9.5 | 240.64
9.5 | 208.56
9.5 | 224.6
9.5 | 240.64
9.5 | 224.6
9.5 | 208.56
9.5 | 224.6
9.5 | 240.64
9.5 | 224.6
9.5 | 240.64
9.5 | 208.56
9.5 | 224.6
9.5 | 240.64
9.5 | 224.6
9.5 | 208.56
9.5 | 224.6
9.5 | 224.6
9.5 | 224.6
9.5 | 208.56
9.5 | 240.64
9.5 | 224.6
9.5 | 240.64
9.5 | 208.56
9.5 | 224.6
9.5 | 240.64
9.5 | 224.6
9.5 | 240.64
9.5 | 224.6
9.5 | 224.6
9.5 | 224.6
9.5 | 240.64
9.5 | 208.56
9.5 | 240.64
9.5 | 224.6

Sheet: Data In
Data In (From USB-SERIAL CH340 (COM9))
Data coming from the current data source will appear below as it is received.
Current Data
TIME | CH1 | CH2 | CH3 | CH4 | CH5 | CH6 | CH7 | CH8 | CH9 | CH10
14:07:48 | 224.6
Historical Data
TIME | CH1 | CH2 | CH3 | CH4 | CH5 | CH6 | CH7 | CH8 | CH9 | CH10
14:07:48 | 224.6
14:07:48 | 224.6
14:07:48 | 208.56
14:07:48 | 240.64
14:07:48 | 224.6
14:07:47 | 240.64
14:07:47 | 224.6
14:07:47 | 240.64
14:07:47 | 224.6
14:07:47 | 240.64
14:07:47 | 224.6
14:07:47 | 208.56
14:07:47 | 240.64
14:07:47 | 224.6
14:07:47 | 240.64
14:07:47 | 208.56
14:07:47 | 224.6
14:07:47 | 240.64
14:07:47 | 224.6
14:07:47 | 208.56
14:07:47 | 224.6
14:07:47 | 224.6
14:07:47 | 224.6
14:07:47 | 224.6
14:07:47 | 208.56
14:07:47 | 224.6
14:07:47 | 240.64
14:07:47 | 224.6
14:07:47 | 208.56
14:07:47 | 240.64
14:07:47 | 224.6
14:07:47 | 240.64
14:07:47 | 208.56
14:07:47 | 224.6
14:07:47 | 240.64
14:07:47 | 224.6
14:07:47 | 208.56
14:07:47 | 240.64
14:07:47 | 224.6
14:07:47 | 240.64
14:07:47 | 224.6
14:07:47 | 240.64
14:07:47 | 224.6
14:07:47 | 224.6
14:07:47 | 224.6
14:07:47 | 192.51
14:07:47 | 224.6
14:07:47 | 240.64
14:07:47 | 224.6
14:07:47 | 208.56
14:07:47 | 240.64
14:07:47 | 224.6
14:07:47 | 240.64
14:07:47 | 208.56
14:07:47 | 224.6
14:07:47 | 240.64
14:07:47 | 224.6
14:07:47 | 240.64
14:07:47 | 224.6
14:07:47 | 240.64
14:07:47 | 224.6
14:07:47 | 224.6
14:07:47 | 208.56
14:07:47 | 240.64
14:07:47 | 224.6
14:07:47 | 240.64
14:07:47 | 208.56
14:07:47 | 224.6
14:07:47 | 240.64
14:07:47 | 224.6
14:07:47 | 208.56
14:07:47 | 240.64
14:07:47 | 224.6
14:07:47 | 240.64
14:07:47 | 224.6
14:07:47 | 208.56
14:07:47 | 224.6
14:07:47 | 240.64
14:07:47 | 224.6
14:07:47 | 208.56
14:07:47 | 240.64
14:07:47 | 224.6
14:07:47 | 240.64
14:07:47 | 208.56
14:07:47 | 224.6
14:07:47 | 240.64
14:07:47 | 224.6
14:07:47 | 208.56
14:07:47 | 224.6
14:07:47 | 224.6
14:07:47 | 224.6
14:07:47 | 224.6
14:07:47 | 224.6
14:07:47 | 240.64
14:07:47 | 224.6
14:07:47 | 240.64
14:07:47 | 208.56
14:07:47 | 224.6
14:07:47 | 240.64
14:07:47 | 224.6
14:07:47 | 208.56
14:07:47 | 240.64
14:07:47 | 224.6
14:07:47 | 240.64
14:07:46 | 208.56
14:07:46 | 240.64
14:07:46 | 224.6
14:07:46 | 240.64
14:07:46 | 224.6
14:07:46 | 240.64
14:07:46 | 224.6
14:07:46 | 240.64
14:07:46 | 224.6
14:07:46 | 208.56
14:07:46 | 240.64
14:07:46 | 224.6
14:07:46 | 240.64
14:07:46 | 208.56
14:07:46 | 224.6
14:07:46 | 240.64
14:07:46 | 224.6
14:07:46 | 208.56
14:07:46 | 224.6
14:07:46 | 240.64
14:07:46 | 224.6
14:07:46 | 240.64
14:07:46 | 208.56
14:07:46 | 224.6
14:07:46 | 240.64
14:07:46 | 224.6
14:07:46 | 208.56
14:07:46 | 224.6
14:07:46 | 224.6
14:07:46 | 224.6
14:07:46 | 208.56
14:07:46 | 240.64
14:07:46 | 224.6
14:07:46 | 240.64
14:07:46 | 208.56
14:07:46 | 224.6
14:07:46 | 240.64
14:07:46 | 224.6
14:07:46 | 240.64
14:07:46 | 224.6
14:07:46 | 224.6
14:07:46 | 224.6
14:07:46 | 240.64
14:07:46 | 208.56
14:07:46 | 240.64
14:07:46 | 224.6

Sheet: Data Out
Data Out (To Device)
Data entered into the channels below will be sent to the currently connected device as a comma-delimited string.
CH1 | CH2 | CH3 | CH4 | CH5 | CH6 | CH7 | CH8 | CH9 | CH10

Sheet: Settings
Workbook Settings
Settings below will affect how data is read into the current workbook from data sources. Clear a field's contents to revert to its default setting.
Data interval (ms) | 150 | 150
Data rows | 15 | 150
Data channels | 10 | 10
Data orientation | Newest last | Newest first
WARNING: Changing settings may result in the loss of content and/or custom formatting in the Data In and Data Out worksheets. Always save before changing values.

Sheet: Manifest
USB-SERIAL CH340 |  |  |  |  |  |  |  |  | {"Channels":[{"Description":null,"Id":null,"IsGhost":false,"Name":null,"Status":"Active","SubChannels":[{"Description":null,"Id":"CH1","IsGhost":false,"Name":"CH1","Status":"Active","SubChannels":[],"UnitOfMeasure":null},{"Description":null,"Id":"CH2","IsGhost":false,"Name":"CH2","Status":"Active","SubChannels":[],"UnitOfMeasure":null},{"Description":null,"Id":"CH3","IsGhost":false,"Name":"CH3","Status":"Active","SubChannels":[],"UnitOfMeasure":null},{"Description":null,"Id":"CH4","IsGhost":false,"Name":"CH4","Status":"Active","SubChannels":[],"UnitOfMeasure":null},{"Description":null,"Id":"CH5","IsGhost":false,"Name":"CH5","Status":"Active","SubChannels":[],"UnitOfMeasure":null},{"Description":null,"Id":"CH6","IsGhost":false,"Name":"CH6","Status":"Active","SubChannels":[],"UnitOfMeasure":null},{"Description":null,"Id":"CH7","IsGhost":false,"Name":"CH7","Status":"Active","SubChannels":[],"UnitOfMeasure":null},{"Description":null,"Id":"CH8","IsGhost":false,"Name":"CH8","Status":"Active","SubChannels":[],"UnitOfMeasure":null},{"Description":null,"Id":"CH9","IsGhost":false,"Name":"CH9","Status":"Active","SubChannels":[],"UnitOfMeasure":null},{"Description":null,"Id":"CH10","IsGhost":false,"Name":"CH10","Status":"Active","SubChannels":[],"UnitOfMeasure":null}],"UnitOfMeasure":null}],"Commands":[],"DataInterval":150,"Id":"07E8272D-434E-4A14-9C19-E1BAF886D7AA","IsGenerated":true,"Name":"USB-SERIAL CH340","Version":null,"BaudRate":115200}
This manifest was generated for the connected device. You can edit the device name and channel data here and the Data In worksheet will be updated.
 | Channels
 |  |  |  |  |  |  | Data Source Id
 |  | Id | Name | Description | Unit of Measure | Active | 07E8272D-434E-4A14-9C19-E1BAF886D7AA | 1
 |  | CH1 | CH1 |  |  | ü | Data Interval (ms)
 |  | CH2 | CH2 |  |  | ü | 150
 |  | CH3 | CH3 |  |  | ü | Baud Rate
 |  | CH4 | CH4 |  |  | ü | 115200
 |  | CH5 | CH5 |  |  | ü
 |  | CH6 | CH6 |  |  | ü
 |  | CH7 | CH7 |  |  | ü
 |  | CH8 | CH8 |  |  | ü
 |  | CH9 | CH9 |  |  | ü
 |  | CH10 | CH10 |  |  | ü

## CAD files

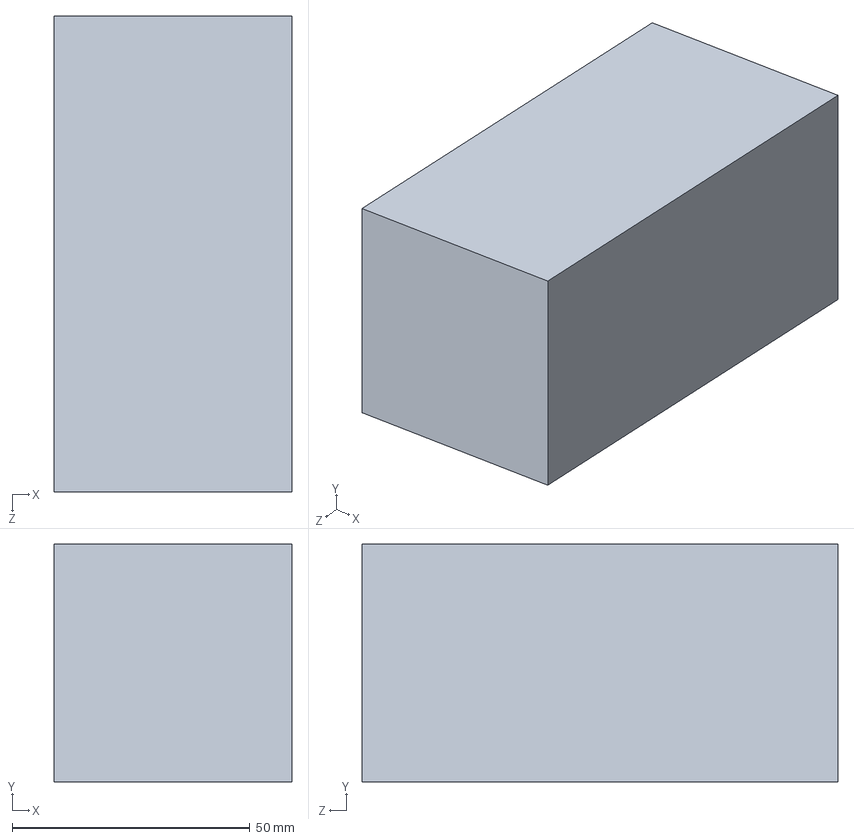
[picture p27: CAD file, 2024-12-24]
Mechanical Design/controllers_Default_sldprt.STEP
50.0 x 50.0 x 100.0 mm

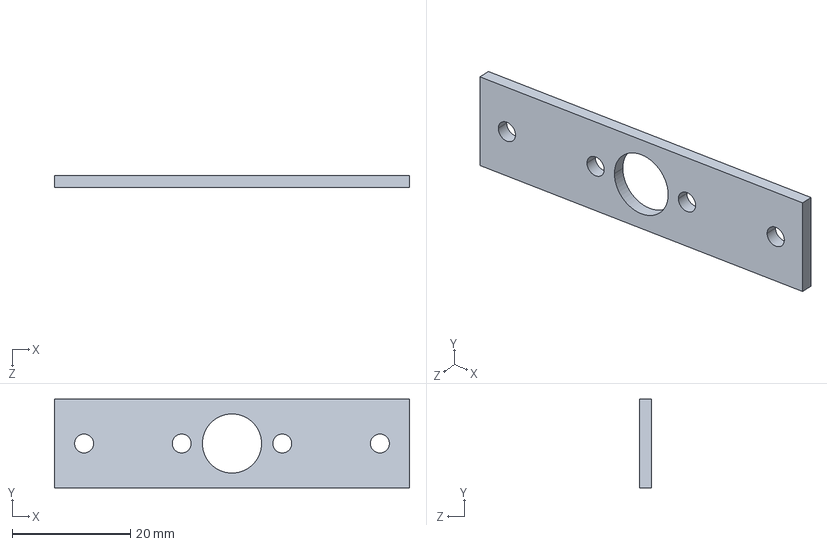
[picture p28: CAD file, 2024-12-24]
Mechanical Design/dc up_block_Default_sldprt.STEP
60.0 x 15.0 x 2.00 mm

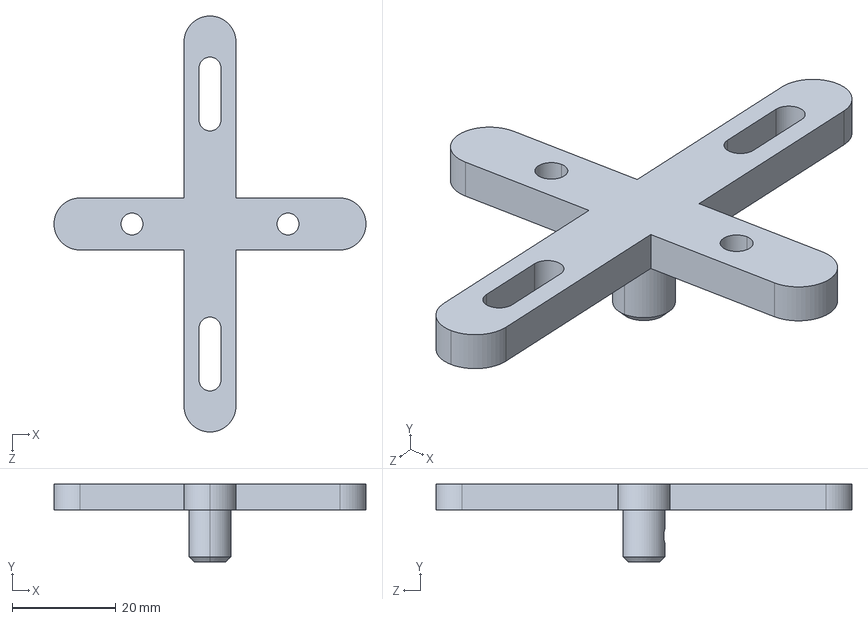
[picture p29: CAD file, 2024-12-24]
Mechanical Design/dc acces_Default_sldprt.STEP
60.0 x 15.0 x 80.0 mm

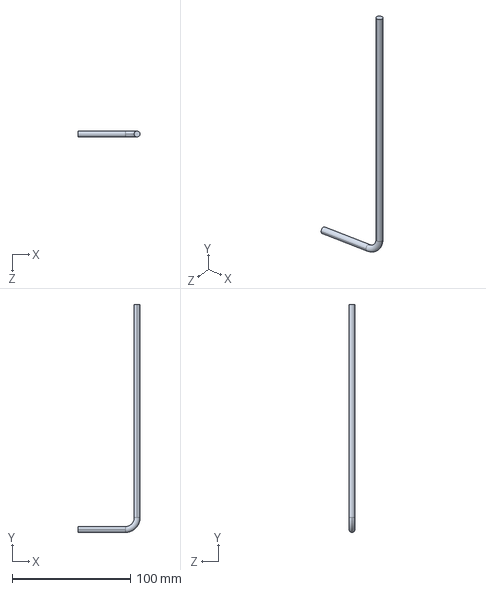
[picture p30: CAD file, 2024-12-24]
Mechanical Design/bendoool_Default_sldprt.STEP
52.5 x 192.5 x 5.00 mm

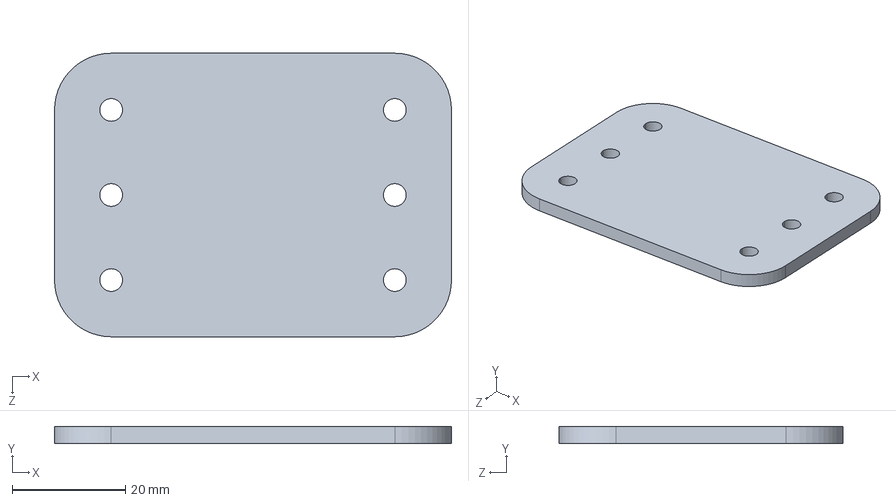
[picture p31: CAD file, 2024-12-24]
Mechanical Design/dc holder_Default_sldprt.STEP
70.0 x 3.00 x 50.0 mm

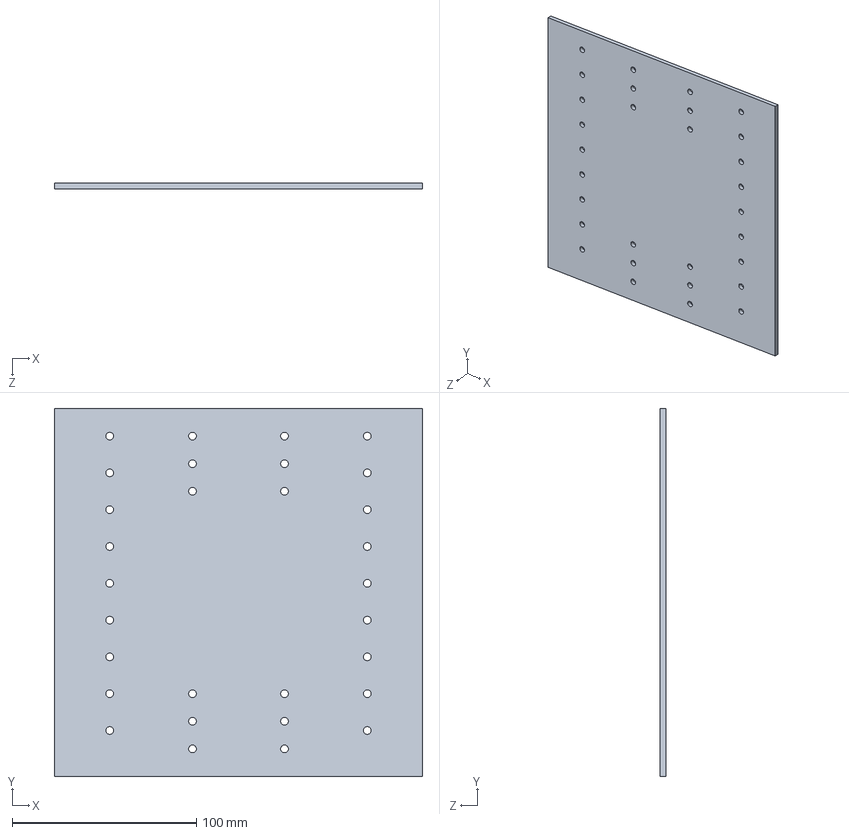
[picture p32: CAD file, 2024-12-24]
Mechanical Design/base_Default_sldprt.STEP
200.0 x 200.0 x 3.00 mm

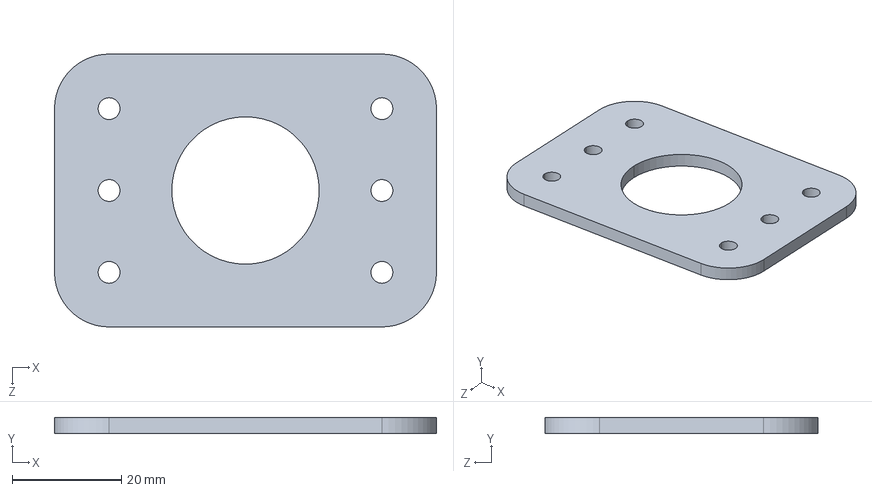
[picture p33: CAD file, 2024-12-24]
Mechanical Design/dc base_Default_sldprt.STEP
70.0 x 3.00 x 50.0 mm

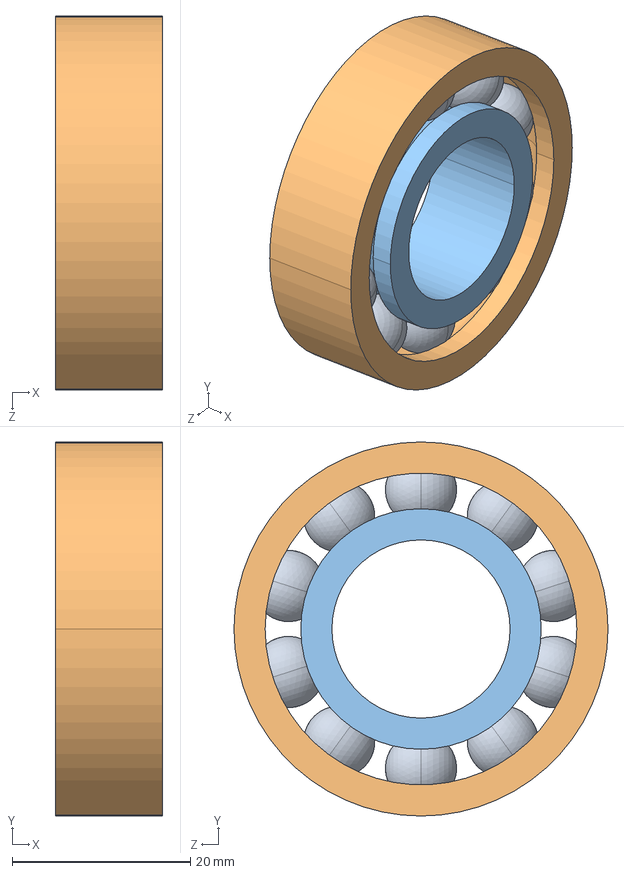
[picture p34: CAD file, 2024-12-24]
Mechanical Design/mbear_Default_sldprt.STEP
12.0 x 42.0 x 42.0 mm

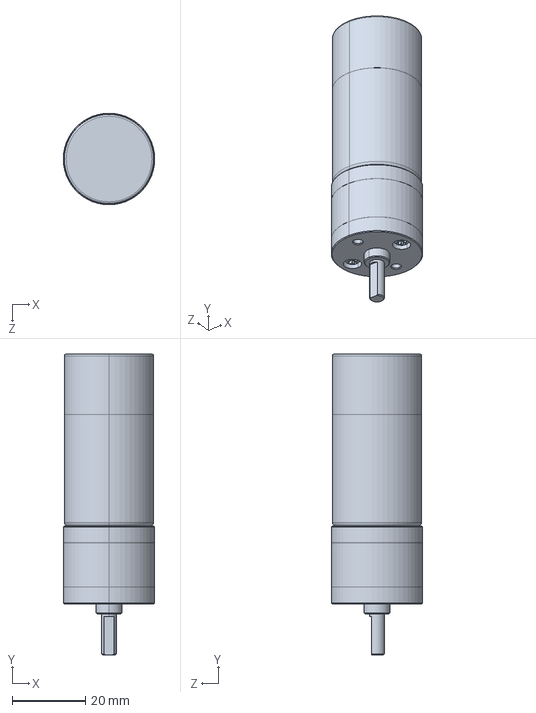
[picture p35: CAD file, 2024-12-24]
Mechanical Design/Geared DC motor with encoder - TS-25GA370H (12V 150RPM).step_Default_sldprt.STEP
25.0 x 82.2 x 25.0 mm

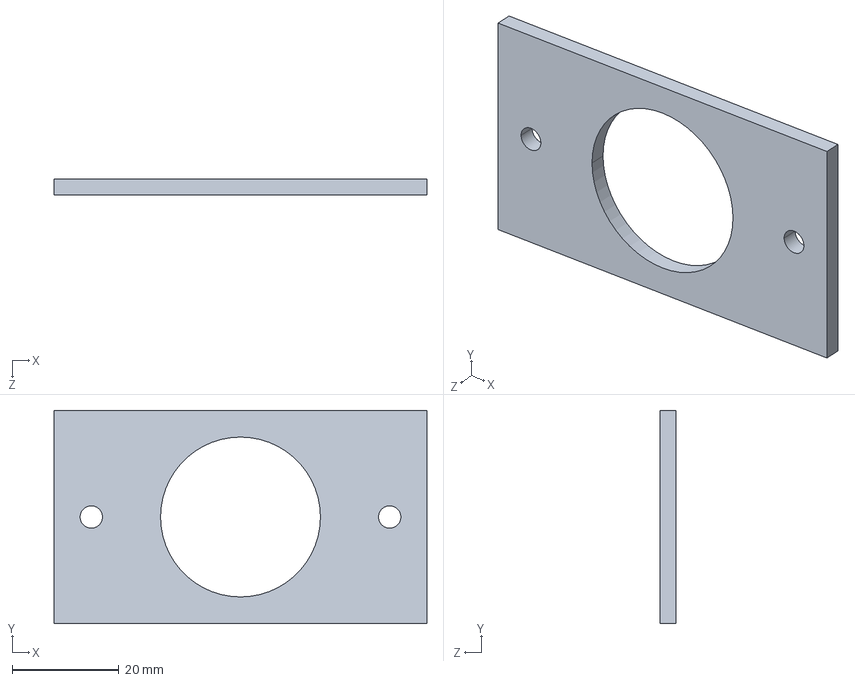
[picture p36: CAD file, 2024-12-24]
Mechanical Design/Part2-Assem1_Default_sldprt.STEP
70.0 x 40.0 x 3.00 mm

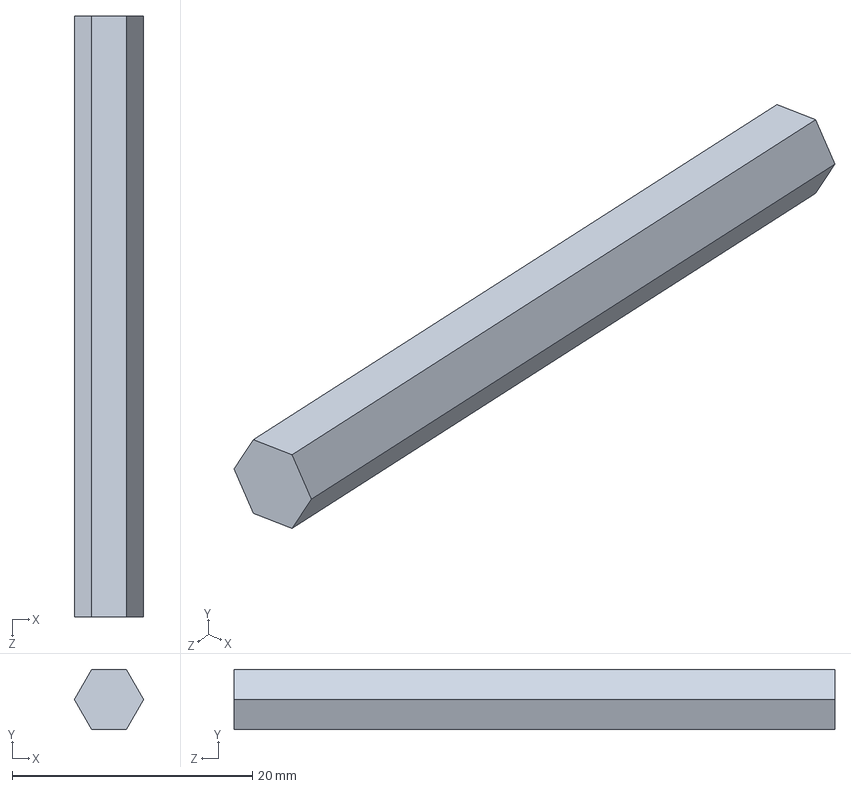
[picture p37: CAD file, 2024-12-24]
Mechanical Design/spacr_Default_sldprt.STEP
5.77 x 5.00 x 50.0 mm

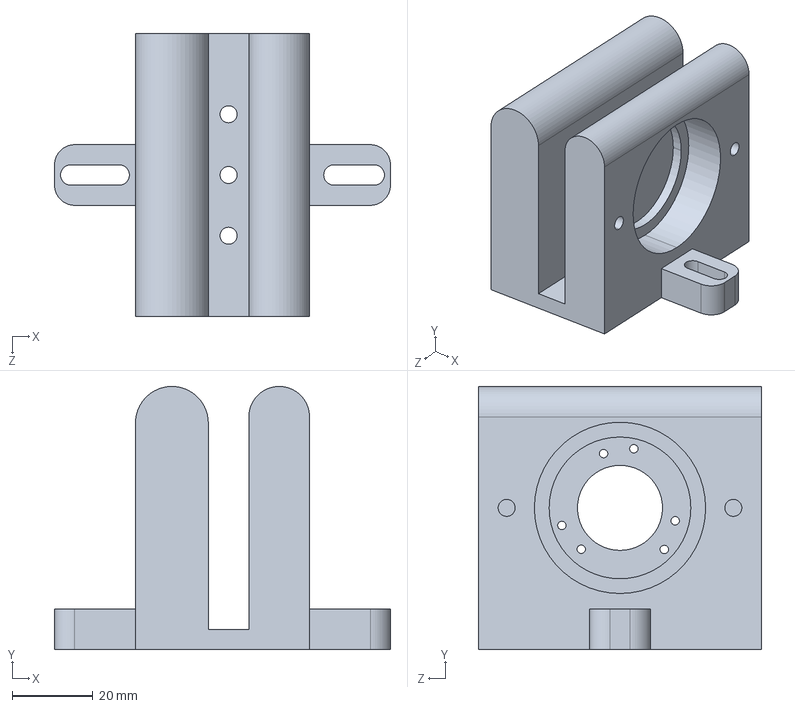
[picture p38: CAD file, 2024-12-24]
Mechanical Design/encoder holder_Default_sldprt.STEP
83.0 x 65.0 x 70.0 mm

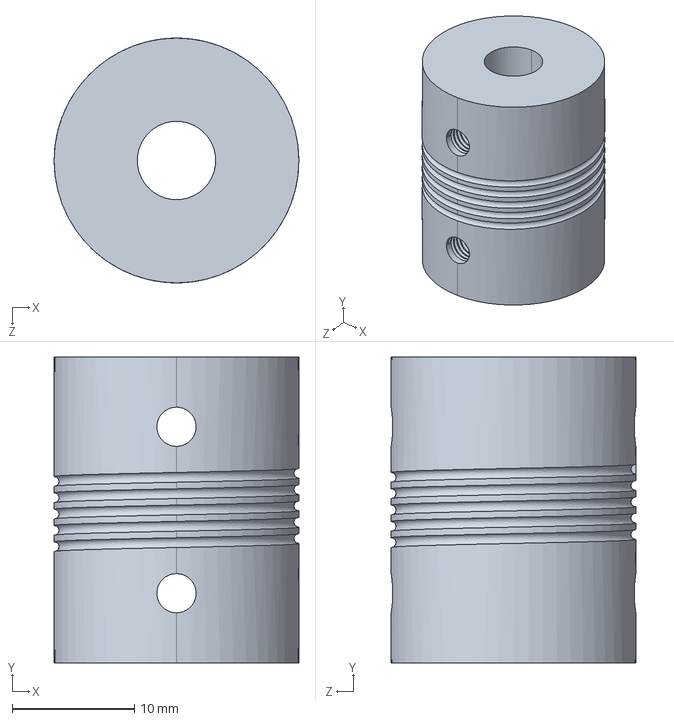
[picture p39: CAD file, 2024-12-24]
Mechanical Design/COPLE CNC_Predeterminado_sldprt.STEP
20.0 x 25.0 x 20.0 mm

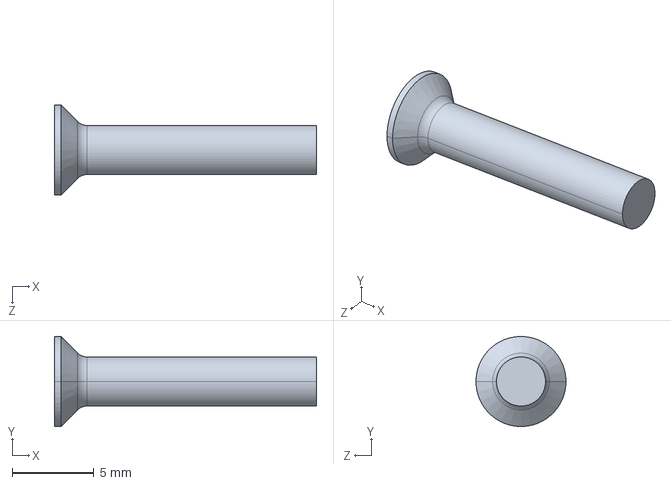
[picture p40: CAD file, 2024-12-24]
Mechanical Design/countersunk flat head cross recess screw1_iso_ISO 7046-1 - M3 x 16 - Z - 16C_sldprt.STEP
16.0 x 5.50 x 5.50 mm

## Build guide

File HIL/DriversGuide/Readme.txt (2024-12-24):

DEVELOPING SIMULINK DEVICE DRIVERS BLOCKS:
------------------------------------------

This package contains a guide that explains how to develop device driver blocks 
(blocks that perform target specific functions such as, for example, analog 
or digital input or output, or talking to specific hardware devices, when 
executed on a target platform). 

In this guide, the first method to develop device drivers is based on the S-Function 
Builder block. Following chapters also describe different methods based respectively 
on the Legacy Code tool, the MATLAB function block, and the System Object block.

In general, the MATLAB Function and System Object approaches tend to work better
for developing complex drivers and blocks that have to be redistributed and masked 
(e.g. because the end user needs to change parameters often). On the other hand the 
S-Function Builder and LCT approaches might be better for developers that are 
more familiar with C/C++ than (Embedded) MATLAB or System Objects and need 
to quickly develop simple drivers that don't have a lot of parameters. 

Note however that the System Object approach does not work for versions prior to R2015a.

Finally note that while the Simulink Support package for Arduino is used to build the 
examples, the method applies to any other supported target. In fact, as of June 2015, 
some examples for the raspberry pi board are also given.

Special thanks to Sebastian Schaefer and Murat Belge for their invaluable help on this last 
version, an in particular for the chapters on the Legacy Code Tool System Objects.

Contents:
---------

Readme.txt              This file
license.txt             License File

DriverGuide.pdf         Guide for developing device driver blocks

output_slsp.mdl         Output device driver block example (digital output, aka digital write)
input_slsp.mdl          Input device driver block example (digital input, aka digital read)
output_slsp_masked.mdl  Maksed S-Function Builder output device driver block

encoder_slsp.mdl        Encoder read example
encoder_slsp_mega.mdl	Example model containing three encoder read blocks

renc2cpp.m              Utility function needed when working with external C++ libraries

LCT                     Folder containing various examples of drivers built using an approach 
                        based on the Legacy Code Tool (LCT) (instead of the S-Function builder).
                        Specifically there are drivers for digital and input and output blocks,
                        analog output, and encoder read blocks).

EML                     Folder containing various examples of drivers built using an approach 
                        based on the MATLAB function block (instead of the S-Function builder).
                        Specifically there are drivers for digital and input and output blocks,
                        analog output, and encoder read blocks).

SYS                     Folder containing various examples of drivers built using an approach 
                        based on the System Object block (instead of the S-Function builder).
                        Specifically there are drivers for digital and input and output blocks,
                        analog output, and encoder read blocks).

src                     Folder containing source code files for the LCT, EML and SYS approaches

S-Function Builder fix for MATLAB 2013b:
----------------------------------------

IMPORTANT: For MATLAB 2013b you will need to apply a fix for the S-Function builder:
Go to the following page: http://www.mathworks.com/support/bugreports/1006532
scroll down to the bottom, and follow the instructions therein (it basically 
comes down to saving the zip file, opening winzip as administrator, and 
unzipping the file in the MATLAB folder (e.g. C:\Program Files\MATLAB\2013b).

Also note that another issue in MATLAB 2013b causes high memory usage on the 
Arduino side, and thus prevents the upload of models that have many blocks 
and/or high memory requirements. This might sometimes be a problem for boards
with smaller memory footprint like the Uno or Nano.

Before trying to run a model:
-----------------------------

First, you have to open each S-Function Builder block and click on "build" 
to generate the MEX-files (this requires that you have a compiler installed, 
see http://www.mathworks.com/support/compilers/current_release/). 

Also, to run the models on an Arduino board you should make sure that the 
simulink support package is installed (just type "targetinstaller" on the 
matlab command line). Also go to "Tools -> Run on Target Hardware -> 
Prepare to Run" or "Tools -> Run on Target Hardware -> Options..." to make 
sure that the settings correspond to your version of Arduino board.

If you are writing a driver, especially one that uses external libraries, 
please have a look at the guide first (especially pages 19 and 20), 
and also look at the encoder examples to see how some problems were 
solved in those cases. 

Additional examples (for different motor shields) can be found here:
http://www.mathworks.com/matlabcentral/fileexchange/46133

Versions:
--------
Version 1.2, 13-Dec-2012, Initial version.
Version 1.4, 23-Apr-2013, Troubleshooting section added.
Version 1.6, 23-Oct-2013, Included drivers for AF Motor Shield V2
Version 1.8, 13-Nov-2013, Included Embedded MATLAB examples 
Version 1.9, 30-Apr-2014, Documented Embedded MATLAB examples 
Version 2.0, 30-Oct-2014, Added System Object approach and examples 
Version 2.2, 02-May-2015, Added Legacy Code Tool approach and examples 
Version 2.4, 08-Jun-2015, Guide rewritten to document all approaches

Copyright 2015, The MathWorks, Inc.

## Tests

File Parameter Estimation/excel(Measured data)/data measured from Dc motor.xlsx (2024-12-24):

T | V | RPM
0 | 0 | 0
0.01 | 4 | 96.26
0.02 | 4 | 96.26
0.03 | 4 | 96.26
0.04 | 4 | 96.26
0.05 | 4 | 80.21
0.06 | 4 | 96.26
0.07 | 4 | 80.21
0.08 | 4 | 96.26
0.09 | 4 | 80.21
0.1 | 4 | 96.26
0.11 | 4 | 96.26
0.12 | 4 | 96.26
0.13 | 4 | 80.21
0.14 | 4 | 96.26
0.15 | 4 | 80.21
0.16 | 4 | 96.26
0.17 | 4 | 96.26
0.18 | 4 | 96.26
0.19 | 4 | 96.26
0.2 | 4 | 80.21
0.21 | 4 | 96.26
0.22 | 4 | 80.21
0.23 | 4 | 96.26
0.24 | 4 | 96.26
0.25 | 4 | 96.26
0.26 | 4 | 80.21
0.27 | 4 | 96.26
0.28 | 4 | 96.26
0.29 | 4 | 80.21
0.3 | 4 | 96.26
0.31 | 4 | 80.21
0.32 | 4 | 96.26
0.33 | 4 | 96.26
0.34 | 4 | 96.26
0.35 | 4 | 80.21
0.36 | 4 | 96.26
0.37 | 4 | 96.26
0.38 | 4 | 96.26
0.39 | 4 | 80.21
0.4 | 4 | 96.26
0.41 | 4 | 96.26
0.42 | 4 | 80.21
0.43 | 4 | 96.26
0.44 | 4 | 80.21
0.45 | 4 | 96.26
0.46 | 4 | 96.26
0.47 | 4 | 80.21
0.48 | 4 | 96.26
0.49 | 4 | 96.26
0.5 | 4 | 80.21
0.51 | 4 | 96.26
0.52 | 4 | 80.21
0.53 | 4 | 96.26
0.54 | 4 | 96.26
0.55 | 4 | 96.26
0.56 | 4 | 80.21
0.57 | 4 | 96.26
0.58 | 4 | 80.21
0.59 | 4 | 96.26
0.6 | 4 | 80.21
0.61 | 4 | 96.26
0.62 | 4 | 96.26
0.63 | 4 | 96.26
0.64 | 4 | 80.21
0.65 | 4 | 96.26
0.66 | 4 | 80.21
0.67 | 4 | 96.26
0.68 | 4 | 96.26
0.69 | 4 | 96.26
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

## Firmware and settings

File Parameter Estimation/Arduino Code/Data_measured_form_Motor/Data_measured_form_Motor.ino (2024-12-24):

// Pin Definitions
const int motorPWM = 6;   // PWM pin connected to motor driver
const int motorIn1 = 8;   // Motor direction pin 1
const int motorIn2 = 9;   // Motor direction pin 2
const int encoderA = 3;   // Encoder channel A (Interrupt pin)
const int encoderB = 5;   // Encoder channel B (Optional, for direction)

volatile long pulseCount = 0;   // Pulse count from the encoder
unsigned long previousMillis = 0;  // Stores the last time data was printed
unsigned long startTime = 0;       // Time at the start of the program

float voltage = 5.0;               // Initial voltage
const float voltageStep = 0.5;     // Voltage step increment
const unsigned long stepInterval = 5000; // Voltage increase interval (1 sec)

// Motor & Encoder Constants
const int PPR = 374;           // Pulses per revolution
const int intervalMs = 10;     // Data printing interval (10 ms)

// Function to handle encoder interrupts
void encoderISR() {
  pulseCount++;
}

void setup() {
  // Initialize Serial Communication
  Serial.begin(115200);

  // Motor setup
  pinMode(motorPWM, OUTPUT);
  pinMode(motorIn1, OUTPUT);
  pinMode(motorIn2, OUTPUT);

  // Set initial motor direction
  digitalWrite(motorIn1, HIGH);
  digitalWrite(motorIn2, LOW);

  // Encoder setup
  pinMode(encoderA, INPUT_PULLUP);
  pinMode(encoderB, INPUT_PULLUP);
  attachInterrupt(digitalPinToInterrupt(encoderA), encoderISR, RISING);

  // Start timing
  startTime = millis();
}

void loop() {
  unsigned long currentMillis = millis();

  // Increase voltage every 1 second
  if (currentMillis - startTime >= stepInterval) {
    voltage += voltageStep;
    if (voltage > 12.0) voltage = 12.0; // Cap voltage at 12V
    startTime = currentMillis;
  }

  // Calculate PWM value from voltage
  int pwmValue = map(voltage * 100, 500, 1200, 106, 255); // Map 5-12V to PWM range (out of 255)

  // Apply PWM to motor
  analogWrite(motorPWM, pwmValue);

  // Calculate and print data every 10ms
  if (currentMillis - previousMillis >= intervalMs) {
    // Calculate RPM
    float rpm = (pulseCount / (float)PPR) * 60000.0 / intervalMs;
    pulseCount = 0; // Reset pulse count

    // Print data
    
    Serial.print(currentMillis);
    Serial.print(", ");
    Serial.print(voltage, 2);
    Serial.print(", ");
    Serial.println(rpm, 2);

    previousMillis = currentMillis;
  }
}

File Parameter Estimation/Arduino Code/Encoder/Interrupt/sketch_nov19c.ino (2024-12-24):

/* YUMO E6B2-CWZ3E OPTICAL ENCODER 
 * 
 * Outputs A & B: quadrature encoder
 * Output Z: homing reference point
 * 
 * Both outputs A and B have 1024 (2^10) rising edge pulses per revolution
 * Change the variable 'pulsesPerRev' to reflect the specifications of your encoder
 * Reference output Z has 1 rising edge pulse per revolution
 * 
 * Wiring:
 * Brown -> 5V
 * Blue -> GND
 * Exposed -> GND
 * Black -> D2 (OUTPUT A)
 * White -> D3 (OUTPUT B)
 * Orange -> D4 (OUTPUT Z)
 * 
 * Libraries used in this program
 * https://github.com/GreyGnome/EnableInterrupt
 * https://github.com/NicksonYap/digitalWriteFast
 */
 
#include <EnableInterrupt.h>          //insufficient number of standard Interrupt pins on the Arduino Uno
#include <digitalWriteFast.h>         

#define encoderA 2
#define encoderB 3
#define encoderZ 4

volatile int countA = 0;
volatile int countB = 0;
volatile int cumulativeCountA = 0;
volatile int cumulativeCountB = 0;
int pulsesPerRev = 1024;     //This variable will is unique to the type of encoder
int Dir = 0;  // 1 = CW
              // 0 = Stationary
              // -1 = CCW

void setup() {
  Serial.begin(9600);
  pinMode(encoderA, INPUT);
  pinModeFast(encoderB, INPUT);
  pinMode(encoderZ, INPUT);  
  enableInterrupt(encoderA, pulseA, RISING);
  enableInterrupt(encoderB, pulseB, RISING);
  enableInterrupt(encoderZ, pulseZ, RISING);
}

void loop() {
  //Serial.print(countA);
  Serial.print('\t');
  //Serial.print(countB);
  Serial.print('\t');
  //Serial.print(cumulativeCountA);
  Serial.print('\t');
  //Serial.print(cumulativeCountB);
  Serial.print('\t');
  Serial.println(Dir);  
}

void checkDirection(){
  if((bool) digitalReadFast(encoderB) ==  HIGH){                             //digitalReadFast() is faster than digitalRead()
    Dir = 1;  
  }
  else{
    Dir = -1;
  }
}

void pulseA(){  
  checkDirection();
  countA += Dir;
  cumulativeCountA += Dir;
}

void pulseB(){  
  countB += Dir;
  cumulativeCountB += Dir;  
}

void pulseZ(){
  countA = 0;   //reset counters at "home" reference point
  countB = 0;
}
